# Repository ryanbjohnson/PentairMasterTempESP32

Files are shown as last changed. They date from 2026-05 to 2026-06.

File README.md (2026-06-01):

# Pentair MasterTemp ESP32 Interface

Open hardware and firmware-planning repository for a draft ESP32-based operating-control interface for the Pentair MasterTemp 125 heater family.

This project is early-stage engineering work. It is not a finished product, not certified, and not approved for connection to a live gas appliance.

## Safety First

- Read [DISCLAIMER.md](DISCLAIMER.md) before using any design file in this repository.
- Do not route or apply line voltage on this PCB.
- Do not add any ESP32-controlled gas-valve output.
- Preserve the OEM ignition control module and its sequencing.
- Keep the heat-request path fail-open with two normally-open relay contacts in series unless a qualified safety review approves a different architecture.
- Treat Wi-Fi, MQTT, Home Assistant, and firmware commands as advisory only. They must never override safety faults.
- A qualified technician and controls/electrical safety reviewer must approve any live-heater test.

## Current Status

The repository currently contains a KiCad scaffold and first-pass schematic capture for major control-board blocks:

- 24 VAC power entry and low-voltage rails.
- Operating-control/ICM interface and dual relay heat-request chain.
- ESP32 supervisor, watchdog, brownout, and relay-gate contract.
- Manual-aligned safety-stack input sheet and static safety gate.
- Field verification and OEM-board photo layout notes.

Remaining work includes final schematic capture, field verification, PCB/schematic parity cleanup, routing, FMEA, bench validation, and professional safety review.

## Repository Map

- `MasterTemp_ESP32_Interface_Preliminary_Design.md`: top-level design intent and safety boundary.
- `pcb/mastertemp_esp32/`: KiCad project.
- `pcb/mastertemp_esp32/docs/`: design notes, manual review, field verification, and layout notes.
- `pcb/mastertemp_esp32/references/`: project-local manuals and visual references used during review.
- `pcb/requirements/`: machine-readable requirements.
- `scripts/`: headless KiCad and test automation.
- `tests/`: scaffold and safety-boundary regression tests.

## Development Quick Start

Install KiCad 8 and Python 3, or use the included dev container.

Run checks:

```bash
./scripts/run-tests.sh
./scripts/kicad-check.sh
```

Open the KiCad project:

```bash
pcb/mastertemp_esp32/mastertemp_esp32.kicad_pro
```

Generated outputs go in ignored `reports/` and `fab/` directories.

## Contributing

Read [CONTRIBUTING.md](CONTRIBUTING.md) before opening issues or pull requests. Contributions that weaken the safety boundary, directly drive the gas valve, add line-voltage routing, or bypass the OEM ignition control module will not be accepted.

Useful first contributions:

- Improve field-verification checklists and documentation.
- Capture missing schematic detail with clear review stubs where assumptions remain open.
- Reduce ERC/DRC/parity issues without masking safety problems.
- Improve tests that enforce the safety boundary.
- Review connector pinout assumptions against installed-heater evidence.

## Security And Safety Reports

Report safety or security issues using GitHub private vulnerability reporting when available, or follow [SECURITY.md](SECURITY.md). Do not publish exploit steps, unsafe bypass instructions, or live-appliance test procedures in public issues.

## License

This repository is licensed under the MIT License. See [LICENSE](LICENSE).

Before first public hardware release, the project owner may choose to move hardware design files to a hardware-specific license such as CERN-OHL-S-2.0; see [docs/licensing.md](docs/licensing.md).

## Publishing Checklist

Before making the repository public or tagging a release, review [docs/open_source_release_checklist.md](docs/open_source_release_checklist.md).

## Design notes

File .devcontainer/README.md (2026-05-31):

# Dev Container Troubleshooting

This dev container is for headless KiCad CLI checks and exports. Use native KiCad on Windows for the GUI.

## KiCad version

The container installs KiCad from the official `ppa:kicad/kicad-8.0-releases` PPA and verifies `kicad-cli` reports version `8.x` during the image build. Rebuild the container after changing `.devcontainer/Dockerfile`:

```text
Dev Containers: Rebuild Container
```

After rebuild, confirm:

```bash
kicad-cli version
```

It should print an `8.x` version. The checked-in PCB file requires KiCad 8 or newer.

## Error: Server is null / cannot connect to docker.sock

Example:

```text
"Server":null
failed to connect to the docker API at unix:///var/run/docker.sock
```

This means VS Code found a Docker client, but no Docker daemon is reachable from the environment where the Dev Containers extension is running.

On Windows with Docker Desktop:

1. Start Docker Desktop.
2. Wait until it says the engine is running.
3. In PowerShell, run:

   ```powershell
   docker version
   docker context ls
   ```

4. If using WSL, enable Docker Desktop WSL integration:

   Docker Desktop -> Settings -> Resources -> WSL Integration -> enable your distro.

5. Restart WSL and VS Code:

   ```powershell
   wsl --shutdown
   ```

6. Reopen this folder in VS Code and rebuild the container.

If the folder is opened through WSL, also check inside that WSL distro:

```bash
docker version
ls -l /var/run/docker.sock
```

The Docker client should show a non-null `Server` section before the dev container can build.

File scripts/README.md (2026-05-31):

# KiCad Scripts

These scripts assume `kicad-cli` is available.

On Windows, install KiCad natively and add its `bin` directory to PATH, or use the VS Code dev container for headless checks.

Typical commands:

```powershell
.\scripts\kicad-check.ps1
.\scripts\kicad-export.ps1
.\scripts\open-kicad-project.ps1
```

Inside the dev container:

```bash
./scripts/run-tests.sh
./scripts/kicad-check.sh
./scripts/kicad-export.sh
```

The dev container is useful for repeatable ERC/DRC/export automation. It is not the preferred way to run the KiCad GUI on Windows.

If VS Code reports `"Server":null` or cannot connect to `/var/run/docker.sock`, Docker Desktop is not reachable from the environment running the Dev Containers extension. Start Docker Desktop, enable WSL integration if the folder is opened through WSL, then run `docker version` until it shows both `Client` and `Server` sections.

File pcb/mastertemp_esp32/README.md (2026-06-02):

# MasterTemp ESP32 KiCad Scaffold

This folder is the KiCad project area for the MasterTemp 125 ESP32 interface board.

The current files are a scaffold, not a completed schematic or board layout. The design intent and safety constraints live in:

- `../../MasterTemp_ESP32_Interface_Preliminary_Design.md`
- `../requirements/mastertemp_esp32_requirements.yaml`

Installed-heater inputs required before electrical release are tracked in `docs/field_input_verification.md`.

The original Pentair board photo reference is tracked in `docs/oem_board_photo_layout_notes.md`; save the image itself as `references/images/original_pentair_control_board_front.jpg` when exporting the chat/IDE attachment.

## Recommended workflow

1. Open `mastertemp_esp32.kicad_pro` in KiCad.
2. Immediately save the project from KiCad once, so your installed KiCad version normalizes the project metadata.
3. Work sheet by sheet, starting with `sheets/power_24vac.kicad_sch`.
4. After each sheet-level change, run ERC.
5. After placement/routing changes, run DRC.
6. Keep all project-local symbols in `libraries/symbols/mastertemp_esp32.kicad_sym`.
7. Keep all project-local footprints in `libraries/footprints/mastertemp_esp32.pretty`.

## Safety notes

- This project is an operating-control interface only.
- Do not add any ESP32-controlled gas-valve output.
- Do not route line voltage on this PCB.
- Preserve the OEM ignition control module and its sequencing.
- The heat-request output must remain dual normally-open relay contacts in series unless a qualified safety review approves another architecture.

## Folder map

- `sheets/`: hierarchical schematic sheets.
- `libraries/`: project-local symbols and footprints.
- `rules/`: layout constraints and DRC notes.
- `docs/`: design workflow notes, pin maps, and review records.
- `references/`: project-local manuals, source documents, and non-release visual references.

## Completion checklist

Use this as the live gate list for moving from scaffold to a reviewable PCB package. Keep each checkbox honest: complete means captured, checked, and reviewed, not merely started.

### Project setup

- [x] KiCad project scaffold exists with root schematic, child sheets, PCB file, local library tables, and scripts.
- [x] Four-layer board scaffold exists with preliminary 160 mm x 100 mm outline and functional placement zones.
- [x] PCB floorplan v0 exists with connector, relay, power, ESP32, analog, and test-pad placement envelopes.
- [x] Local MasterTemp 125 Rev C PDF electrical pages were reviewed and summarized in `docs/mastertemp125_rev_c_manual_review.md`.
- [x] Candidate sourced BOM and first-pass footprint placement exist for control-board circuitry.
- [x] PCB-side draft nets and first-pass relay contact-chain routing are applied and documented.
- [x] Headless KiCad `ERC` and `DRC` automation runs in the dev container.
- [x] Repository-level scaffold tests exist under `tests/`.
- [ ] KiCad project metadata has been opened and normalized once in the target GUI KiCad version.
- [ ] Generated `reports/` and `fab/` outputs are regenerated from the final release candidate.

### Inputs to close before electrical release

- [ ] Exact MasterTemp 125 model revision, serial/date range, and connected/non-connected variant are recorded.
- [ ] Field input verification record is complete and reviewed in `docs/field_input_verification.md`.
- [x] Rev C manual connector groups are reflected in draft requirements and floorplan.
- [ ] Heater harness pinout is verified from the installed unit and matching manual revision.
- [ ] 24 VAC transformer no-load and loaded voltages are measured.
- [ ] Water thermistor resistance curve is confirmed.
- [ ] Stack flue sensor electrical type and valid/fault ranges are confirmed.
- [ ] Enclosure, mounting holes, standoff height, cable-entry direction, and service clearances are selected.
- [ ] Certification/review path is chosen, including current applicable pool-heater and automatic-control standards.

### Schematic capture

- [ ] `power_24vac`: connector, fuse/PTC, MOV/TVS, bridge, VRAW bulk, 5 V supply, 3.3 V supply, power-good/brownout.
- [ ] `icm_interface`: manual-aligned operating-control connector, dual series normally-open relay contacts, coil drivers, flyback, AC opto sense, TH feedback, ICM terminal reference.
- [ ] `esp32_supervisor`: ESP32 module, programming header, watchdog, reset supervisor, I2C, relay-enable logic.
- [ ] `safety_inputs`: Fireman's Switch, PS, HLS, ES1, AGS static chain, AFS dynamic monitor, dry-contact isolated sense.
- [ ] `thermistor_sfs`: first-pass ADC/window-comparator architecture captured; final thermistor/SFS values and thresholds remain field-open.
- [ ] `ui_remote`: Pool/Common/Spa external-control dry-contact sense only; keypad/display/buzzer/status LED design remains out of scope.
- [ ] ERC has zero unreviewed violations after each sheet is captured.
- [ ] All symbols have footprints assigned or documented as no-fit/test-only.

### Safety review

- [ ] OEM ignition control module remains responsible for ignition, flame proving, and gas-valve sequencing.
- [ ] No ESP32 or board output can directly energize the gas valve.
- [ ] No line-voltage nets, connectors, labels, or routing exist on this PCB.
- [ ] Two normally-open relay contacts are in series in the `TH` heat-request path.
- [ ] Relay drive drops out on ESP32 reset, watchdog timeout, brownout, firmware fault, OTA, static safety open, invalid sensor, and relay feedback fault.
- [ ] AFS is treated as a dynamic airflow-proving input, not as a static pre-fire interlock.
- [ ] Preliminary FMEA covers welded relay, optocoupler failure, stuck ADC, brownout oscillation, firmware deadlock, and miswire cases.

### PCB layout

- [x] First-pass placement envelopes follow the zone plan in `rules/layout_constraints.md`.
- [x] Draft connector envelopes follow Rev C Figure 24 operating-control groups.
- [x] Candidate footprints are placed according to first-pass sourced part numbers.
- [x] Critical relay contact-chain PCB nets are named and first-pass routed.
- [ ] Footprints are synchronized to final schematic symbols and netlist.
- [x] ESP32 antenna keepout has no copper, components, or nearby metal-obstructing placement in the draft placement.
- [ ] Relay contact and 24 VAC control paths use assigned net classes and visible separation from logic.
- [ ] Field-side optocoupler pins face connectors and logic-side pins face MCU/expander circuitry.
- [ ] Thermistor/SFS analog traces avoid relay coils, AC sense, ESD discharge paths, and buck switch nodes.
- [x] Test pads exist for `VRAW`, `+5V`, `+3V3`, watchdog, safety chain, relay coils, TH feedback, and VAL sense.
- [x] Silkscreen warnings are present and readable.
- [x] DRC has zero unreviewed violations and schematic parity passes for the current draft.

### Fabrication and validation

- [ ] Schematic PDF, PCB plots, Gerbers, drill files, BOM, and placement outputs are generated.
- [ ] Bench test procedure is executed with an isolated 24 VAC transformer.
- [ ] Every required heat-request drop-out case is tested and recorded.
- [ ] Relay feedback/welded-contact detection is tested.
- [ ] `VAL` sense-only behavior is tested.
- [ ] 24-hour relay/sensor soak test is completed.
- [ ] Qualified technician review is complete before any live-heater connection.

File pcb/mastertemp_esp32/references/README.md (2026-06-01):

# References

Project-local reference materials live here.

- `manuals/`: vendor manuals, datasheets, and other source documents used for design review.
- `images/`: visual references such as original-board photos, connector photos, and field-verification images.

Reference materials support design review only. They do not close release gates unless the relevant field-verification record identifies the source, evidence, and reviewer.

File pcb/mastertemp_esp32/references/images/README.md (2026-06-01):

# Reference Images

Keep non-release visual references for board review here.

Expected files:

- `original_pentair_control_board_front.jpg`: user-provided front-side photo of the original MasterTemp 125/Pentair control board, received 2026-06-01. This chat attachment was analyzed in `../../docs/oem_board_photo_layout_notes.md`; save the original image here when exporting attachments from the chat or IDE.

These images are design references only. Do not treat markings, connector order, or component values from a photo as verified release data without matching them against the installed heater and manual revision.

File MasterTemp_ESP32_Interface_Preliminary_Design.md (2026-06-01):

# Pentair MasterTemp 125 ESP32 Interface Board - Preliminary Design Package

Status: preliminary engineering design for review only. This is not a certified gas-appliance control, not a release-to-manufacturing package, and not an installation instruction. A licensed/qualified pool-heater service technician and a controls engineer familiar with ANSI Z21.56/CSA 4.7 gas-fired pool-heater requirements must review, test, and approve any hardware before it is connected to a live heater.

## 1. Safety Boundary

This design is an operating-control/interface board. It must preserve the factory ignition control module (ICM) and must not directly drive the gas valve. The board only requests heat by switching the existing 24 VAC call-for-heat signal to `TH` on the ICM through isolated, normally-open relay contacts.

Hard requirements:

- No line voltage is routed on this PCB.
- No output from the ESP32 is allowed to energize the gas valve.
- Loss of ESP32 power, watchdog heartbeat, 3.3 V rail, 5 V rail, 24 VAC input, or firmware control opens the heat request.
- Two normally-open relay contacts are placed in series in the `TH` call-for-heat path.
- Hardware interlocks disable heat independently of MQTT, Wi-Fi, web UI, Home Assistant, and OTA.
- Safety switches are never bypassed in firmware.
- Final installation must keep the OEM heater grounding/bonding and line-voltage compartment unchanged.

Manufacturer facts used for this design:

- The MasterTemp 125 is a 120/240 VAC gas-fired heater using a Class II 24 VAC transformer for the control system.
- The Pentair manual identifies `VAL`, `TH`, `IND`, `GND`, `24VAC`, `FS`, thermistor, safety-switch, membrane-pad, and external pool/spa/common interface points.
- Pentair documents that the Fireman's Switch completes the heater 24 V AC control-board circuit, is sized around 24 VAC at 0.5 A, and must not receive line voltage.
- Pentair troubleshooting checks for 24 VAC between `TH` and `GND` immediately after a call for heat, and for 24 VAC on `VAL`/gas-valve-related signals only during the ignition trial.
- Pentair's connected-heater parts matrix lists old control board `42002-0007S` as basic PCBA superseded by kit `461105`; the older ICM `42001-0052S` is superseded by `476223`.

Sources:

- Pentair MasterTemp 125 Installation and User's Guide, Rev. C: https://www.pentair.com/content/dam/extranet/aquatics/pool-pad-pro-assets/heaters-%26-heat-pumps/inground-heaters/mastertemp-125-heater/MasterTemp%20125%20Installati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
  - Local checked-in copy: `pcb/mastertemp_esp32/references/manuals/mastertemp_125_installation_users_guide_english_rev_c.pdf`
- Pentair MasterTemp/Max-E-Therm connected-heater parts matrix: https://www.pentair.com/content/dam/extranet/nam/pentair-pool/residential/parts-sheets/heaters/mastertemp-max-e-therm-parts-matrix-connected-heater-update-v1.pdf
- Pentair electrical-system replacement parts sheet showing 42002-0007S and factory sensors: https://www.pentair.com/content/dam/extranet/nam/pentair-pool/residential/parts-sheets/heaters/MaxETherm_Heater_Electrical_System.pdf

## 2. System Architecture

Functional blocks:

1. 24 VAC input protection and power conversion.
2. ESP32-WROOM controller with external watchdog/supervisor.
3. Isolated 24 VAC sense inputs for ICM and heater-status signals.
4. Protected dry-contact sensing for remote Pool/Common/Spa and local UI.
5. Safety-switch sensing and hardware heat-enable chain.
6. Thermistor and stack-flue-sensor analog measurement through protected ADC channels.
7. Dual series relay heat-request output to ICM `TH`.
8. Relay feedback sensing for welded-contact or unexpected `TH` voltage detection.
9. Local UI header, optional OLED/I2C display, LEDs, buzzer, UART/JTAG programming.

Important sequencing note: `AFS` is a proving switch. It is expected to prove combustion-air flow after blower operation begins, so the firmware must check it for sane idle/run behavior instead of blindly requiring it closed before the call for heat. The hardware chain should include Fireman's Switch/remote enable, water pressure, high-limit, AGS, and analog overtemperature comparators as static pre-fire enables. `AFS` is monitored dynamically and can be included in a delayed run-enable circuit only after blower/IND activity is detected.

## 3. Schematic-Level Design

### Page 1 - 24 VAC Input and Power

Connector `J1 POWER`, 3.5 or 5.08 mm keyed pluggable terminal:

| Pin | Net | Description |
| --- | --- | --- |
| 1 | `VAC24_A` | Heater transformer secondary |
| 2 | `VAC24_B` | Heater transformer secondary |
| 3 | `CHASSIS_SHIELD` | Optional shield/bond reference, no DC tie by default |

Power path:

- `VAC24_A` -> `F1` 0.5 A fuse/PTC -> `MOV1` across `VAC24_A_FUSED`/`VAC24_B`.
- `D1` bridge rectifier converts `VAC24_A_FUSED`/`VAC24_B` to `VRAW`/`PGND_RAW`.
- `TVS1` bidirectional or post-bridge TVS clamps transients.
- `C1/C2` bulk capacitance on `VRAW`; use 63 V or 100 V ratings.
- `U1` high-voltage buck: `VRAW` to `+5V`.
- `U2` synchronous buck: `+5V` to `+3V3`.
- `U3` 3.3 V reset supervisor drives `ESP32_EN` and `HEAT_ENABLE_HW`.
- `U4` watchdog supervisor requires ESP32 heartbeat before relay drive is allowed.

Nominal voltage calculation:

- 24 VAC RMS nominal gives about 34 V peak before bridge drops.
- 24 VAC at +10 percent gives about 37 V peak.
- Unloaded Class II transformers can exceed nominal; all `VRAW` parts should be 63 V minimum, with the 5 V buck rated 80-100 V.

### Page 2 - MCU, Supervisors, and Digital I/O

Controller:

- `U5`: Espressif `ESP32-WROOM-32E-N16`.
- `U6`: Microchip `MCP23017-E/SS` I/O expander for LEDs, buttons, and non-time-critical opto inputs.
- `U7`: TI `ADS1115IDGSR` external ADC for thermistor, SFS, and rail monitoring.
- `U16/U17`: hardware window comparators for thermistor and SFS plausibility gates.

Supervisor logic:

- ESP32 outputs `WDI_HEARTBEAT` at 10-50 Hz only while the firmware is in a healthy non-OTA runtime loop.
- `U4 /WDO` must be inactive for heat enable.
- `U3 /RESET` must be inactive for heat enable.
- Relay drive is permitted only when:
  `HEAT_CMD_GPIO` AND `WATCHDOG_OK` AND `BROWNOUT_OK` AND `SAFETY_STATIC_OK` AND `NOT_OTA` AND `NOT_FAULT_LOCKOUT`.

Recommended hardware implementation:

- Use a small logic gate such as `SN74LVC1G08DBVR` for each relay-enable path.
- Use pull-downs on every relay-driver MOSFET gate.
- Make default gate state low during ESP32 reset/boot.

### Page 3 - Safety Inputs and Static Hardware Chain

Use two circuits for each safety contact where practical:

1. A low-current isolated sense input so firmware knows which safety opened.
2. A hardware safety-enable path so the relay coil cannot energize if a critical safety is open.

Critical static chain:

`FIREMAN_CLOSED` -> `PS_CLOSED` -> `HLS_CLOSED` -> `AGS_CLOSED` -> `ES1_CLOSED_OR_JUMPERED` -> `THERMISTOR_RANGE_OK` -> `SFS_RANGE_OK` -> `SAFETY_STATIC_OK`.

Notes:

- `PS` should close only with valid pump flow/pressure.
- `HLS` and `AGS` are closed in normal operation and open on overtemperature.
- `ES1` is spare; follow the exact heater wiring diagram for whether it is jumpered.
- `SFS` is not a simple low-resistance dry contact in all variants; treat it as an analog/high-impedance sensor and verify against the exact heater harness.
- `AFS` is dynamic. Firmware must confirm "open when idle" and "closed after blower/IND proves airflow." If `AFS` opens during firing, drop `TH` immediately.

Per-contact sense circuit, dry contact:

- Isolated 5 V wetting source `+5V_ISO` from `U8` isolated DC/DC.
- Contact closure drives an optocoupler LED through 2.2 k to 4.7 k.
- Optocoupler transistor pulls an ESP32/MCP23017 input low.
- Add 100 nF debounce capacitor on the logic side, then debounce again in firmware.
- Add ESD/TVS at harness connector.

### Page 4 - Thermistor and Stack Flue Sensor

Thermistor input:

- `J3_THERM_A/B` two-pin protected input.
- 10.0 k, 0.1 percent pull-up to `+3V3_ADC`.
- 1 k series resistor into `ADS1115_AIN0`.
- 100 nF C0G/X7R to analog ground at ADC pin.
- Low-leakage ESD clamp to rails.
- Firmware rejects open, short, out-of-range, implausible rate-of-change, and ADC saturation.
- Independent window comparator output `THERMISTOR_RANGE_OK` must drop heat enable on open, short, or overtemperature threshold even if firmware is stuck.

SFS input:

- `J3_SFS_A/B` two-pin protected high-impedance input.
- Use a high-value divider/current source suitable for the installed SFS type.
- Buffer with low-bias op amp before ADC if the selected excitation impedance is above 1 Mohm.
- Add a hardware comparator window `SFS_RANGE_OK` so extreme SFS open/short/fault disables heat without firmware.
- Final resistor values must be validated with the exact Pentair SFS installed on the heater.

### Page 5 - 24 VAC Sense Inputs

Use AC-input optocouplers for:

- `ICM_TH_SENSE`
- `ICM_IND_SENSE`
- `ICM_VAL_SENSE`
- `ICM_24VAC_SENSE`
- Optional `TH_OUTPUT_FEEDBACK`

Typical circuit:

- Field signal pair -> two series input resistors -> `H11AA1M` input.
- Start value: 2 x 12.1 k, 0.25 W, 1 percent in series for a 24 VAC signal.
- Logic transistor side: 10 k pull-up to 3.3 V, Schmitt input or RC pulse stretcher.
- Firmware treats AC sense as a pulse train and declares signal present only after several valid half-cycles.

Do not use these sense circuits to source current into the ICM. They are monitor-only.

### Page 6 - Call-for-Heat Output

The heat-request output is a dry, isolated, dual-relay series path:

`ICM_24VAC_SOURCE` -> `K1_COM` -> `K1_NO` -> `K2_COM` -> `K2_NO` -> `ICM_TH`.

Relay gating:

- `K1` coil: controlled by firmware heat command plus watchdog/brownout gate.
- `K2` coil: controlled by static safety hardware chain plus firmware heat command gate.
- Both relays are normally open.
- Loss of board power opens both relays.
- A stuck relay is detected by `TH_OUTPUT_FEEDBACK` when firmware expects off.

Relay contact rating:

- Minimum 30 VAC / 1 A resistive.
- Use relays with substantially higher agency-rated contact capacity where possible.
- Contacts are switching only the heater's 24 VAC control circuit, never line voltage.

Gas valve:

- No board output is provided for direct gas-valve drive.
- `VAL` is monitor-only through an isolated AC sense input.

### Page 7 - External Controls and UI

Remote Pool/Common/Spa:

- `POOL_REMOTE`, `COMMON_REMOTE`, `SPA_REMOTE` are dry-contact sense inputs.
- The board supplies wetting current through isolated sensing only.
- Do not accept externally supplied voltage on these terminals.
- If Pool and Spa are both asserted, enter conflict fault and keep heat off.

Local controls:

- `BTN_POOL`
- `BTN_SPA`
- `BTN_OFF`
- `BTN_UP`
- `BTN_DOWN`
- `BTN_RESET_SERVICE`

Display:

- I2C OLED/LCD header on `DISPLAY_SDA`, `DISPLAY_SCL`, `+3V3`, `GND`.
- Optional buzzer and WS2812/status LED header, powered from `+5V` with level-shifted data if used.

## 4. Connector Pinout Table

### J1 - Power

| Pin | Signal | Type |
| --- | --- | --- |
| 1 | `24VAC_IN_1` | 24 VAC transformer secondary |
| 2 | `24VAC_IN_2` | 24 VAC transformer secondary |
| 3 | `CHASSIS_SHIELD` | Shield/bond reference, normally isolated from logic |

### J2 - Ignition Control Module Interface

| Pin | Signal | Type |
| --- | --- | --- |
| 1 | `ICM_24VAC_SOURCE` | 24 VAC source for relay contact COM |
| 2 | `ICM_GND_REF` | 24 VAC reference for sense only |
| 3 | `ICM_TH_OUT` | Relay-switched 24 VAC call for heat to TH |
| 4 | `ICM_TH_SENSE_A` | Isolated AC sense |
| 5 | `ICM_IND_SENSE_A` | Isolated AC sense |
| 6 | `ICM_VAL_SENSE_A` | Isolated AC sense |
| 7 | `ICM_SENSE_REF` | Return/reference for AC sense inputs |

### J3 - Safety and Sensors

Use paired terminals where possible so the board can preserve the field wiring instead of relying on chassis/common returns.

| Pin | Signal | Type |
| --- | --- | --- |
| 1 | `PS_A` | Water pressure switch |
| 2 | `PS_B` | Water pressure switch |
| 3 | `HLS_A` | High-limit switch |
| 4 | `HLS_B` | High-limit switch |
| 5 | `ES1_A` | Extra switch/jumper |
| 6 | `ES1_B` | Extra switch/jumper |
| 7 | `AFS_A` | Air-flow proving switch |
| 8 | `AFS_B` | Air-flow proving switch |
| 9 | `AGS_A` | Automatic gas shutoff switch |
| 10 | `AGS_B` | Automatic gas shutoff switch |
| 11 | `SFS_A` | Stack flue sensor |
| 12 | `SFS_B` | Stack flue sensor |
| 13 | `THERM_A` | Water thermistor |
| 14 | `THERM_B` | Water thermistor |

### J4 - Remote Controls

| Pin | Signal | Type |
| --- | --- | --- |
| 1 | `POOL_REMOTE` | Dry-contact sense |
| 2 | `COMMON_REMOTE` | Dry-contact common |
| 3 | `SPA_REMOTE` | Dry-contact sense |
| 4 | `FIREMAN_A` | Fireman's Switch loop |
| 5 | `FIREMAN_B` | Fireman's Switch loop |

### J5 - Local UI

| Pin | Signal | Type |
| --- | --- | --- |
| 1 | `BTN_POOL` | Momentary input |
| 2 | `BTN_SPA` | Momentary input |
| 3 | `BTN_OFF` | Momentary input |
| 4 | `BTN_UP` | Momentary input |
| 5 | `BTN_DOWN` | Momentary input |
| 6 | `BTN_RESET` | Momentary input |
| 7 | `UI_GND` | Logic ground |
| 8 | `DISPLAY_SDA` | I2C |
| 9 | `DISPLAY_SCL` | I2C |
| 10 | `+3V3_UI` | Display/UI power |
| 11 | `BUZZER` | Output |
| 12 | `STATUS_LED_DATA` | Output |

### J6 - Programming/Service

| Pin | Signal |
| --- | --- |
| 1 | `+3V3` |
| 2 | `GND` |
| 3 | `ESP_TX0` |
| 4 | `ESP_RX0` |
| 5 | `EN` |
| 6 | `GPIO0_BOOT` |

## 5. Candidate BOM

This BOM is a starting point for schematic capture. It is not procurement-approved; verify package, availability, lifecycle, agency ratings, and derating before layout release.

| Ref | Qty | Part number | Manufacturer | Function |
| --- | --- | --- | --- | --- |
| U5 | 1 | `ESP32-WROOM-32E-N16` | Espressif | Wi-Fi MCU module |
| U1 | 1 | `LM5164YDRCR` | Texas Instruments | 100 V input buck, 5 V rail |
| U2 | 1 | `AP63203WU-7` | Diodes Inc. | 5 V to 3.3 V buck |
| U3 | 1 | `TPS3839G33DBZR` | Texas Instruments | 3.3 V brownout supervisor |
| U4 | 1 | `TPS3823-33DBVR` | Texas Instruments | Watchdog/reset supervisor |
| U6 | 1 | `MCP23017-E/SS` | Microchip | I/O expander |
| U7 | 1 | `ADS1115IDGSR` | Texas Instruments | 16-bit I2C ADC |
| U8 | 1 | `NXE1S0505MC-R7` | Murata | Isolated 5 V for dry-contact wetting |
| U16-U17 | 2 | `TLV6700DDCR` | Texas Instruments | Window comparators for sensor validity gates |
| U18 | 1 | `OPA333AIDBVR` | Texas Instruments | Low-bias analog buffer for SFS if needed |
| U9-U12 | 4 | `H11AA1M` | onsemi | AC optocoupler sense |
| U13-U15 | 3 | `TLP293-4(GB,E)` | Toshiba | Quad optocouplers for dry contacts |
| K1-K2 | 2 | `G5V-1-DC5` | Omron | Series NO heat-request relays |
| Q1-Q2 | 2 | `AO3400A` | Alpha & Omega | Relay low-side drivers |
| D1 | 1 | `MB10S-13-F` | Diodes Inc. | Bridge rectifier |
| D2-D3 | 2 | `SS14` | Vishay/Diodes Inc. | Relay flyback diodes |
| F1 | 1 | `0451.500MRL` | Littelfuse | 0.5 A input fuse |
| MOV1 | 1 | `V47ZA1P` | Littelfuse | 24 VAC surge clamp |
| TVS1 | 1 | `SMBJ51CA` | Littelfuse | Post-bridge transient clamp |
| C1 | 1 | `EEU-FR1J471L` | Panasonic | 470 uF, 63 V bulk capacitor |
| C2-C3 | 2 | `CGA5L3X7R2A475K160AE` | TDK | 4.7 uF, 100 V input ceramic |
| L1 | 1 | `744773470` | Wurth Elektronik | 47 uH buck inductor, validate with U1 |
| L2 | 1 | `74438323022` | Wurth Elektronik | 2.2 uH buck inductor |
| R_AC | 8 | 12.1 k, 0.25 W, 1% | Yageo/Vishay | AC opto input resistors, two per sense |
| R_WET | as needed | 2.2 k to 4.7 k, 0.1 W | Yageo/Vishay | Dry-contact opto LED resistors |
| R_TH | 1 | 10.0 k, 0.1%, 25 ppm | Vishay | Thermistor pull-up |
| R_GATE | 2 | 100 ohm | Any | MOSFET gate resistors |
| R_PD | 2 | 100 k | Any | Relay gate pull-downs |
| J1-J6 | as needed | Phoenix Contact MSTB/MC keyed pluggable series | Phoenix Contact | Field connectors |
| ENC | 1 | `1554H2GYCL` or similar | Hammond | Polycarbonate enclosure, gasketed |

Possible alternates:

- Use an ESP32-S3-WROOM module if more RAM, USB, or safer ADC isolation strategy is needed.
- Use force-guided safety relays if a certification path requires positively guided contacts and contact monitoring.
- Use a certified external 24 VAC to 5 V DC module instead of the onboard buck if thermal/EMC qualification becomes the bigger risk.

## 6. Firmware Pin Map

ESP32 pins:

| Signal | GPIO | Notes |
| --- | --- | --- |
| `I2C_SDA` | GPIO21 | ADS1115, MCP23017, OLED |
| `I2C_SCL` | GPIO22 | I2C clock |
| `HEAT_K1_CMD` | GPIO25 | Relay K1 command, gated in hardware |
| `HEAT_K2_CMD` | GPIO26 | Relay K2 command, gated in hardware |
| `WDI_HEARTBEAT` | GPIO27 | External watchdog input |
| `ICM_TH_PRESENT` | GPIO34 | Input-only, opto pulse |
| `ICM_IND_PRESENT` | GPIO35 | Input-only, opto pulse |
| `ICM_VAL_PRESENT` | GPIO32 | Opto pulse |
| `ICM_24VAC_PRESENT` | GPIO33 | Opto pulse |
| `MCP23017_INT` | GPIO39 | Input-only interrupt |
| `ADS1115_ALERT` | GPIO36 | Input-only alert |
| `BUZZER_PWM` | GPIO14 | Optional |
| `WS2812_DATA` | GPIO13 | Optional level-shifted LED |
| `UART0_TX` | GPIO1 | Service programming |
| `UART0_RX` | GPIO3 | Service programming |
| `BOOT` | GPIO0 | Bootloader only, pulled up |
| `EN` | EN | Supervisor reset |

Avoid using ESP32 strapping pins for relay commands. Relay outputs must remain deasserted during bootloader, reset, crash, OTA, and brownout.

MCP23017 allocation:

- GPA0-GPA5: local buttons.
- GPA6-GPA7: remote Pool/Spa conflict inputs.
- GPB0-GPB5: safety contact sense status.
- GPB6-GPB7: service/heating/status LEDs.

ADS1115 allocation:

- AIN0: water thermistor divider.
- AIN1: SFS measurement.
- AIN2: 5 V rail monitor.
- AIN3: VRAW scaled monitor or spare.

## 7. Firmware State Machine

### Power-up self-test

- Keep K1 and K2 off.
- Hold `WDI_HEARTBEAT` inactive until initialization completes.
- Validate NVS settings CRC and temperature calibration bounds.
- Validate thermistor range and ADC sanity.
- Validate SFS range and comparator state.
- Confirm no relay feedback is present with relay commands off.
- Confirm no conflicting Pool/Spa commands.
- Confirm AFS is in its expected idle state; a stuck AFS enters service fault.

### Idle

- Display current water temperature and selected mode.
- Publish MQTT telemetry.
- Monitor all safeties continuously.
- Permit OTA only in Idle and only when no post-purge or anti-short-cycle timer is active.

### Heat demand pending

Conditions required:

- Pool or Spa mode selected, not Off.
- Setpoint above measured water temperature plus hysteresis.
- Setpoint no higher than 104 deg F / 40 deg C default maximum.
- Fireman's Switch closed.
- Water pressure switch closed.
- HLS and AGS closed.
- Thermistor and SFS valid.
- No active lockout.
- Pool and Spa inputs not both active.
- Watchdog, brownout, and relay-feedback tests pass.

### Ignition sequence monitor

- Energize K1/K2 only after all gates are true.
- Confirm `TH` feedback appears.
- Watch `IND`/blower-related sense if connected.
- Require AFS to prove within a configured timeout after blower/IND activity.
- Monitor `VAL` as sense-only; do not drive it.
- If `VAL` appears when no valid `TH` command exists, enter service lockout.
- If ignition sequence times out, drop `TH`, log fault, and lock out or retry according to configured policy.

### Heating

- Maintain heat request only while all permissives remain true.
- Drop K1/K2 immediately on safety fault, thermistor/SFS invalid reading, overtemperature, watchdog event, brownout, relay-feedback mismatch, remote conflict, or user Off.
- Log runtime and ignition count.
- Publish heating state and active fault state over MQTT.

### Post-purge / cooldown

- Keep K1/K2 off.
- Continue monitoring blower/IND/VAL feedback.
- Do not re-fire until the post-purge observation has completed and the anti-short-cycle timer has expired.
- Manual default: 45 s blower/post-purge observation and 5 min anti-short-cycle delay.

### Fault lockout

Manual reset required for:

- High-limit or AGS fault.
- SFS invalid or overtemperature.
- Thermistor open/short/out-of-range.
- Watchdog reset while heating.
- Brownout while heating.
- Relay feedback indicates welded/stuck contact.
- `VAL` present without commanded heat.
- AFS stuck closed at idle or failure to prove after blower start.

Timed retry may be allowed only for benign demand/timeouts after professional review. Do not auto-retry high-limit, gas-valve, relay-feedback, or sensor-validity faults.

## 8. MQTT and Home Assistant

Suggested MQTT topics:

- `pentair/mastertemp125/state`
- `pentair/mastertemp125/availability`
- `pentair/mastertemp125/water_temp_f`
- `pentair/mastertemp125/pool_setpoint_f`
- `pentair/mastertemp125/spa_setpoint_f`
- `pentair/mastertemp125/mode/set`
- `pentair/mastertemp125/fault`
- `pentair/mastertemp125/runtime_seconds`
- `pentair/mastertemp125/ignition_count`

Rules:

- Wi-Fi failure must never block local safety operation.
- MQTT commands are advisory UI commands only; they cannot override a safety fault.
- OTA is refused unless state is Idle, heat relays are off, `VAL` is not present, and post-purge/anti-short-cycle timers are clear.
- Home Assistant discovery should expose climate control, binary sensors for safeties, and diagnostic sensors, but no entity should bypass local lockouts.

## 9. Power Budget

Estimated worst-case board load:

| Load | Voltage | Current | Power |
| --- | --- | --- | --- |
| ESP32 Wi-Fi burst | 3.3 V | 500 mA peak | 1.65 W peak |
| ESP32 average | 3.3 V | 120-180 mA | 0.4-0.6 W |
| Relays K1/K2 | 5 V | 60 mA total typical | 0.3 W |
| Optos/isolated wetting | 5 V | 50-100 mA | 0.25-0.5 W |
| OLED/status LEDs | 3.3/5 V | 50-150 mA | 0.2-0.6 W |
| Margin | - | - | 1 W |

Recommended supply ratings:

- 5 V rail: at least 1.2 A continuous.
- 3.3 V rail: at least 700 mA peak, 400 mA continuous.
- Thermal design: verify at 50 deg C ambient inside the heater control compartment.
- Brownout threshold: disable relays before ESP32 operation becomes undefined.

## 10. PCB Layout Requirements

Board stack:

- Prefer 4-layer PCB: signal/top, solid ground, power, signal/bottom.
- 2-layer acceptable only after EMC/noise testing, with short high-current loops and careful grounding.

Zones:

- Zone A: 24 VAC field wiring, fusing, bridge, surge protection.
- Zone B: `VRAW` buck converter and bulk capacitor.
- Zone C: logic/ESP32/ADC/I2C.
- Zone D: relay contacts and ICM connector.
- Zone E: external remote/UI field connector.

Clearance:

- No line voltage on PCB.
- Maintain at least 6.4 mm clearance between any connector area that could be miswired to field wiring and SELV logic where practical.
- Add isolation slots under/around optocouplers and relay contact areas.
- Maintain clear silkscreen boundary: "24 VAC CONTROL ONLY - NO LINE VOLTAGE".
- Keep ESP32 antenna beyond copper pour and away from relay/transformer wiring.

Routing:

- Route `VRAW` buck input loop compactly.
- Keep thermistor/SFS traces away from relay coils, buck switch node, and AC sense inputs.
- Use star/quiet analog ground into ADC reference region.
- Place TVS parts at connector entry.
- Put relay contacts in series with wide, separated traces; label COM/NO clearly.
- Provide test pads for `+5V`, `+3V3`, `VRAW`, `WATCHDOG_OK`, `SAFETY_STATIC_OK`, `K1_COIL`, `K2_COIL`, `TH_FEEDBACK`, `VAL_SENSE`.

Silkscreen warnings:

- "NO LINE VOLTAGE ON CONTROL TERMINALS"
- "GAS VALVE MONITOR ONLY - DO NOT DRIVE"
- "24 VAC CLASS II CONTROL POWER ONLY"
- "INSTALL/SERVICE BY QUALIFIED TECHNICIAN"
- "VERIFY WIRING AGAINST HEATER MANUAL BEFORE POWER"

## 11. Enclosure and Mounting

Recommended:

- Mount inside the existing low-voltage/control-board compartment only if line-voltage separation and temperature limits are preserved.
- Use a gasketed polycarbonate enclosure if mounted separately: Hammond `1554H2GYCL` or equivalent.
- Use nylon or metal standoffs with bonded ground only where required by heater enclosure practice.
- Do not tie ESP32 digital ground to chassis/bonding conductor unless an EMI/safety review intentionally adds a defined network, such as Y-cap/RC/TVS strategy allowed by applicable standards.
- All external wires should use 105 deg C rated insulation where they share routing with heater wiring, matching the manual's service guidance.

## 12. Bench Test Procedure

Before heater connection:

1. Visual inspect PCB for solder bridges, wrong polarity capacitors, and relay contact clearance.
2. Confirm no continuity between relay contact field nets and ESP32 logic ground.
3. Power from an isolated bench 24 VAC transformer only.
4. Verify `VRAW`, `+5V`, and `+3V3` at low, nominal, and high simulated transformer input.
5. Hold ESP32 in reset; confirm K1/K2 contacts remain open.
6. Load blank firmware or stop heartbeat; confirm watchdog disables relay drive.
7. Force brownout; confirm relay coils drop out before ESP32 resets unpredictably.
8. Command heat with safety chain open; confirm K1/K2 do not both close.
9. Simulate each safety input open/closed and verify correct diagnostic state.
10. Simulate AFS stuck closed at idle; confirm lockout.
11. Simulate blower/IND then AFS closure; confirm allowed sequence.
12. Simulate thermistor normal, open, short, high temperature, and implausible jumps.
13. Simulate SFS normal, open, short, and overtemperature/fault values.
14. Apply Pool and Spa remote contacts independently; confirm dry-contact behavior.
15. Assert Pool and Spa simultaneously; confirm conflict fault and no heat request.
16. Confirm relay output switches only isolated 24 VAC to `TH`, never line voltage.
17. With relays off, inject unexpected `TH` feedback; confirm welded-contact/external-voltage fault.
18. With `VAL` sense active and no heat command, confirm service lockout.
19. Confirm OTA is rejected during any non-idle state.
20. Run 24-hour soak test with cycling relays and synthetic sensors.

On-heater test, qualified technician only:

1. Compare every harness wire against the exact MasterTemp 125 wiring diagram revision for the installed heater.
2. Confirm line power is off and locked out before wiring.
3. Confirm no line-voltage conductor is present on any board terminal.
4. First power the board from heater 24 VAC with heat output disconnected.
5. Verify sensor readings and safety states match actual heater conditions.
6. Connect `TH` output with gas shut off/manual valve off for initial sequence testing.
7. Verify `TH` appears only during valid call for heat and drops immediately on each simulated safety opening.
8. Verify blower/IND and AFS sequence.
9. Verify `VAL` is monitored only and never driven by this board.
10. Restore gas only after wiring, safeties, post-purge, and shutdown behavior are verified.
11. Perform combustion, gas-pressure, leak, venting, and CO tests according to the heater manual and local code.

## 13. Safety Validation Checklist

- [ ] The OEM ICM remains installed and handles ignition, flame proving, and gas-valve sequencing.
- [ ] ESP32 cannot directly energize gas valve.
- [ ] K1 and K2 are normally open and series-connected in the `TH` request path.
- [ ] Relay contacts open with no board power.
- [ ] Relay contacts open with ESP32 reset.
- [ ] Relay contacts open with watchdog timeout.
- [ ] Relay contacts open with 3.3 V brownout.
- [ ] Relay contacts open with Fireman's Switch open.
- [ ] Relay contacts open with PS open.
- [ ] Relay contacts open with HLS or AGS open.
- [ ] Relay contacts open on invalid thermistor.
- [ ] Relay contacts open on invalid SFS.
- [ ] AFS stuck-closed-at-idle fault is detected.
- [ ] AFS failure-to-prove fault is detected.
- [ ] Pool/Spa simultaneous command fault is detected.
- [ ] Unexpected `TH` voltage with relays off is detected.
- [ ] Unexpected `VAL` voltage without heat request is detected.
- [ ] Wi-Fi/MQTT/Home Assistant cannot override safety lockout.
- [ ] OTA cannot run while heating, post-purge, or anti-short-cycle timer is active.
- [ ] Silkscreen and connector labels explicitly warn against line voltage.
- [ ] Final design has professional review and heater-specific wiring verification.

## 14. Open Items Before CAD Release

1. Confirm exact MasterTemp 125 revision, serial date, connected/non-connected version, and harness connector pinout.
2. Measure actual transformer no-load and loaded voltage in the installed heater.
3. Confirm thermistor resistance curve and SFS electrical characteristics for the installed sensor revision.
4. Decide whether this is a true replacement PCBA or an interposer that keeps parts of the OEM operating control.
5. Choose certification target and required standards before final relay/watchdog/safety-chain design.
6. Validate relay contact rating, creepage, and failure-mode requirements with the certification path.
7. Perform FMEA for relay welded contact, optocoupler failure, ADC stuck reading, brownout oscillation, and firmware deadlock.
8. Create actual KiCad/Altium schematic, PCB, ERC/DRC, fabrication drawings, test fixture, and firmware after the above are closed.

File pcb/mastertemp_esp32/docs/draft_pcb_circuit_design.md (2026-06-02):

# Draft PCB Circuit Design Pass

Date: 2026-06-02

Status: PCB-side draft routing and net assignment. This records the control-board circuit intent now applied to the board file by `scripts/apply-draft-pcb-nets.py`. Full release still requires symbol-level schematic capture and schematic-to-PCB synchronization.

## Scope

This pass covers the control board only:

- 24 VAC operating-control interface.
- Dual normally-open heat-request relay contacts in series.
- Sense-only diagnostic nets for `VAL`, `IND`, `TH`, `24VAC`, and `GAS`.
- External Pool/Common/Spa dry-contact input naming.
- Thermistor and SFS signal naming.
- ESP32, supervisor, ADC, I/O expander, relay-driver, and test-point net naming.

The keypad, membrane pad electronics, display, buzzer, and status LED remain out of scope.

## Applied Critical Contact Chain

| Function | PCB net | Applied pads |
| --- | --- | --- |
| ICM 24 VAC source into first relay contact | `ICM_24VAC_SOURCE` | `J2.5`, `K1.2` |
| Relay-to-relay series link | `HEAT_CHAIN_K1_K2` | `K1.3`, `K2.2` |
| Heat request output back to TH | `TH_HEAT_REQUEST_OUT` | `K2.3`, `J2.2` |

The first-pass board route connects the relay contact chain with 0.60 mm copper. `ICM_24VAC_SOURCE` is routed on `F.Cu`; `HEAT_CHAIN_K1_K2` and `TH_HEAT_REQUEST_OUT` are routed on `B.Cu` to avoid same-layer crossings with the relay coil and flyback routing.

## Applied Relay Driver Nets

| Function | PCB net | Applied pads |
| --- | --- | --- |
| K1 coil low-side node | `K1_COIL_LOW` | `K1.1`, `Q1.3`, `TP6.1` |
| K2 coil low-side node | `K2_COIL_LOW` | `K2.1`, `Q2.3`, `TP7.1` |
| Relay coil supply | `+5V_RELAY` | `K1.5`, `K2.5` |
| K1 gate drive placeholder | `RELAY_K1_GATE_DRIVE` | `R22.1` |
| K2 gate drive placeholder | `RELAY_K2_GATE_DRIVE` | `R23.1` |
| K1 gate command | `RELAY_K1_GATE` | `R22.2`, `Q1.1`, `R10.1` |
| K2 gate command | `RELAY_K2_GATE` | `R23.2`, `Q2.1`, `R11.1` |
| K1 gate pulldown return | `GND` | `R10.2` |
| K2 gate pulldown return | `GND` | `R11.2` |
| Driver source reference | `GND` | `Q1.2`, `Q2.2` |

The relay coil low-side traces, local `+5V_RELAY` rail between relay coil pins, K1/K2 flyback diode connections, MOSFET source grounds, first-pass relay-gate pulldowns, and first-pass relay-gate series resistors are routed. R10/R11/R22/R23 values remain TBD pending the ESP32/supervisor relay-drive review.

## Applied Low-Voltage Routing

- `VRAW` is first-pass routed from the bridge rectifier output to the local buck input capacitor, bulk reservoir capacitor, VRAW test point, U1 VIN pads, and the R28 raw-rail monitor top resistor.
- `PGND_RAW` is first-pass routed from the bridge rectifier return to the local buck input capacitor, bulk reservoir capacitor, and U1 PGND area with via-assisted local return stitching. The final high-current return shape still needs placement/layout review.
- `SW_5V` and `BST_5V` are first-pass routed through the 5 V buck switch/bootstrap loop, with the bootstrap net using a via-assisted back-layer hop to avoid the switch node.
- `+5V` is first-pass routed from the 5 V buck output/feed divider area to the 3.3 V regulator input decoupling node and TP2.
- `+3V3` is first-pass routed from the 3.3 V regulator output to its output capacitor, ADC supply, supervisor supply, ESP32 supply pad, 3.3 V test point, and the external-control Spa/Pool pullup resistor supply pads.
- `GND` now includes first-pass via-assisted routing from the ADC/local logic ground spine to the supervisor ground pins, ESP32 ground pad, relay-driver MOSFET sources, and the remote optocoupler/RC-filter ground cluster.
- `WATCHDOG_OK` is routed from the supervisor output to TP4 with a via-assisted back-layer hop around the local `+3V3` supervisor rail.
- `U6` is now schematic-owned as a local `MCP23017_SS` symbol. Its `VDD`, `VSS`, `SDA`, `SCL`, address pins, and reset pin are captured and first-pass routed; `A0`/`A1`/`A2` are tied low and `~RESET` is tied high. GPA0 is assigned to `VAL_OPTO_GPIO`, GPA1 is assigned to `TH_OPTO_GPIO`, GPA2 is assigned to `IND_OPTO_GPIO`, and GPA3 is assigned to `VAC24_OPTO_GPIO`; the remaining GPIO and interrupt pins remain explicitly no-connected until the expansion topology is assigned. R25/R26 add schematic-owned 0805 I2C pullup placeholders from `+3V3` to `I2C_SDA`/`I2C_SCL`, placed near U6 with short routed stubs to the shared U6/U7 bus.
- `VAC24_A_FUSED` now ties the fuse/MOV island to the bridge/TVS protection island using a back-layer bridge and front-layer via handoff.
- `VAL_SENSE_AC` is routed from J2 to TP9 as a perimeter diagnostic trace. It remains monitor-only and does not drive the gas valve.
- `REMOTE_SPA_SENSE` and `REMOTE_POOL_SENSE` are locally routed from their pullup resistors through the RC filter capacitors to the optocoupler output pins.
- `U8` is now schematic-owned as the Murata `NXE1S0505MC-R7` isolated 5 V converter. Per the NXE1 pin table, pad 1 is `GND`/`-Vin`, pad 3 is `+5V`/`+Vin`, pad 7 is `COMMON_LINE`/`-Vout`, pad 8 is `ISO_REMOTE_5V`/`+Vout`, and pad 14 remains no-connect. The isolated output is first-pass routed to the external-control wetting supply and common return.
- `U9`-`U12` now use a real project-local `H11AA1M` AC-input phototransistor optocoupler symbol instead of a generic DIP placeholder. The onsemi/Fairchild pinout is captured as pins 1-2 AC input, pin 3 NC, pin 4 emitter, pin 5 collector, and pin 6 base. `U11` has its VAL monitor transistor output side captured: emitter to `GND`, collector to `VAL_OPTO_GPIO` on MCP23017 GPA0, with R12 as a schematic-owned 0805 pullup placeholder to `+3V3`. Its AC input side is captured through two 0805 current-limit placeholders: `VAL_SENSE_AC` -> `R8` -> `VAL_OPTO_LIMIT_A` -> `R9` -> `VAL_OPTO_INPUT` -> `U11.1`, with `U11.2` returned to `ICM_GND_REF`. `U9` repeats that monitor pattern for TH: `TH_HEAT_REQUEST_OUT` -> `R13` -> `TH_OPTO_LIMIT_A` -> `R14` -> `TH_OPTO_INPUT` -> `U9.1`, with `U9.2` returned to `ICM_GND_REF`; U9 emitter returns to `GND`, collector connects to `TH_OPTO_GPIO` on MCP23017 GPA1, and R15 pulls the collector to `+3V3`. `U10` repeats the same pattern for IND: `IND_SENSE_AC` -> `R16` -> `IND_OPTO_LIMIT_A` -> `R17` -> `IND_OPTO_INPUT` -> `U10.1`, with `U10.2` returned to `ICM_GND_REF`; U10 emitter returns to `GND`, collector connects to `IND_OPTO_GPIO` on MCP23017 GPA2, and R18 pulls the collector to `+3V3`. `U12` now repeats the same sense-only pattern for the 24 VAC source: `ICM_24VAC_SOURCE` -> `R19` -> `VAC24_OPTO_LIMIT_A` -> `R20` -> `VAC24_OPTO_INPUT` -> `U12.1`, with `U12.2` returned to `ICM_GND_REF`; U12 emitter returns to `GND`, collector connects to `VAC24_OPTO_GPIO` on MCP23017 GPA3, and R21 pulls the collector to `+3V3`. R8/R9/R12/R13/R14/R15/R16/R17/R18/R19/R20/R21 final resistance, power/leakage, filtering, surge, and sensing margin remain review items.
- `R10` and `R11` are now schematic-owned 0805 relay-gate pulldown placeholders. They tie `RELAY_K1_GATE` and `RELAY_K2_GATE` to `GND` locally at Q1/Q2 so the MOSFET gates have a defined off-state once final drive values are selected. `R22` and `R23` are schematic-owned 0805 series-gate placeholders that split the schematic-only relay-gate logic outputs into `RELAY_K1_GATE_DRIVE`/`RELAY_K2_GATE_DRIVE` and the local MOSFET gate nodes.
- `SPA_LINE` and `POOL_LINE` are first-pass routed from the remote optocoupler input side to the external-control connector, `ISO_REMOTE_5V` is sourced from U8 and locally routed between the Spa/Pool remote wetting resistors, `COMMON_LINE` is sourced from U8 isolated return to J5.2, and the optocoupler LED anode nets are locally routed from the wetting resistors to the optocouplers.
- `U14` is now a schematic-owned thermistor AFE placeholder with a matching `SOT-23-6` PCB footprint. Its thermistor input, ADC output, window-sense, analog rail, and analog return nets are first-pass routed on the inner layers with short local pad escapes. R24 adds a schematic-owned 0805 thermistor pullup placeholder from `+3V3_ADC` to `THERMISTOR_ADC`, and C9 adds a schematic-owned 0805 ADC filter placeholder from `THERMISTOR_ADC` to `AGND`; both are locally routed near the U14/U7 analog cluster. Threshold/reference component values and the final thermistor/SFS analog topology remain review items.
- `U18` is the schematic-owned SFS buffer/excitation placeholder. R27 now reserves a routed 0805 series/protection element from the J3 `SFS_INPUT` field terminal to `SFS_FIELD_INPUT`, and C10 reserves a routed 0805 ADC-side filter from `SFS_ADC` to `AGND`. This keeps the SFS input path physically present while leaving the unknown `SFS_RETURN_OR_REF`, excitation, clamp strategy, and final value choices open until the installed SFS is characterized.
- ADS1115 AIN2 is now named and routed as `VRAW_MONITOR_ADC` instead of the stale `TH_FEEDBACK_ADC` label. R28 reserves the top divider resistor from `VRAW` near TP1, while R29 and C11 reserve the bottom divider/filter elements from `VRAW_MONITOR_ADC` to `AGND` in the analog cluster. The monitor node reaches U7 AIN2 with via-assisted inner-layer routing; final divider ratio, voltage/power ratings, leakage, filtering, and firmware scaling remain review items.
- R30/R31 add routed 0805 pullup placeholders from `+3V3` to `THERMISTOR_RANGE_OK` and `SFS_RANGE_OK` at U16/U17. These preserve physical pullup locations for the comparator outputs while leaving final values, population policy, output polarity, and static-safety logic review open.
- R32-R39 add routed 0805 threshold-divider placeholders from `+3V3_ADC` to `AGND` for the U16/U17 low/high comparator references. R32/R33 create `THERM_LOW_REF_TBD`, R34/R35 create `THERM_HIGH_REF_TBD`, R36/R37 create `SFS_LOW_REF_TBD`, and R38/R39 create `SFS_HIGH_REF_TBD`. These nets are routed into the comparator inputs with via-assisted local escapes; final resistor values, tolerances, hysteresis policy, and fault thresholds remain tied to measured thermistor/SFS curves and TLV6700 behavior.

## Applied Connector Nets

| Connector | Pad order |
| --- | --- |
| `J1` 24 VAC input | `24VAC_A`, `24VAC_B`, `EARTH_SHIELD_REF` |
| `J2` operating control | `VAL_SENSE_AC`, `TH_HEAT_REQUEST_OUT`, `IND_SENSE_AC`, `ICM_GND_REF`, `ICM_24VAC_SOURCE`, `FIREMAN_24VAC`, `FIREMAN_SWITCH_RETURN` |
| `J3` safety stack | `PS_SWITCH`, `HLS_SWITCH`, `ES1_SWITCH`, `AFS_SWITCH_DYNAMIC`, `AGS_SWITCH`, `SFS_INPUT`, `GAS_MONITOR_ONLY` |
| `J4` thermistor | `THERMISTOR_A`, `THERMISTOR_B` |
| `J5` external control | `SPA_LINE`, `COMMON_LINE`, `POOL_LINE` |

## Verification State

- ERC report: zero violations after the MCP23017 core-pin capture and placeholder ownership cleanup.
- PCB DRC report: zero violations and zero unconnected items after this pass.
- Silkscreen cleanup moved dense/internal references and long floorplan notes off the manufacturing silkscreen while preserving the notes in the board file.
- Schematic parity report: zero issues after bringing all currently placed footprints under schematic ownership. U6 now has its MCP23017 supply/I2C/address/reset core captured, U8 now has its isolated-supply input/output pins captured, U11 now has a routed VAL optocoupler input resistor chain, output to MCP23017 GPA0, and R12 logic-side pullup placeholder, U9 now has a routed TH optocoupler input resistor chain, output to MCP23017 GPA1, and R15 logic-side pullup placeholder, U10 now has a routed IND optocoupler input resistor chain, output to MCP23017 GPA2, and R18 logic-side pullup placeholder, U12 now has a routed 24 VAC optocoupler input resistor chain, output to MCP23017 GPA3, and R21 logic-side pullup placeholder, R10/R11 now have routed relay-gate pulldown placeholders, R22/R23 now have relay-gate series placeholders, R24/C9 now have routed thermistor divider/filter placeholders, R25/R26 now have routed I2C pullup placeholders, R27/C10 now have routed SFS input/filter placeholders, R28/R29/C11 now have routed VRAW monitor divider/filter placeholders, R30/R31 now have routed comparator-output pullup placeholders, R32-R39 now have routed comparator threshold-divider placeholders, and U9-U12 now have real H11AA1M pin identities. Conceptual relay-gate and static-safety review blocks are schematic-only so they no longer collide with physical optocoupler references.

## Next Real Electrical Work

- Continue replacing uncommitted placeholder blocks with real symbols, hierarchical pins, labels, footprints, and values.
- Assign remaining U6 MCP23017 GPIO/interrupt usage and review firmware-safe reset behavior; R25/R26 now reserve I2C pullup positions, but final values still depend on bus capacitance, speed, leakage, and any external pullups.
- Review and value the U11 VAL, U9 TH, U10 IND, and U12 24 VAC monitor input resistors, pullups, filtering, surge tolerance, CTR margin, and base-pin handling.
- Add/value remaining passives: buck feedback/compensation/filter parts, ADC protection, SFS return/excitation/buffer parts, comparator threshold/hysteresis values for R32-R39, and final values/ratings for the existing optocoupler, relay-gate, thermistor, I2C, SFS, and VRAW monitor placeholders.
- Run KiCad update-PCB-from-schematic and replace this PCB-side draft net application with schematic-derived nets.
- Complete schematic synchronization, copper zones, fabrication outputs, and qualified safety review.

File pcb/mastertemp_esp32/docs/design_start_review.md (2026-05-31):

# Design Start Review

Date: 2026-05-31

## Current Project State

This repository is a KiCad scaffold for a Pentair MasterTemp 125 ESP32 operating-control interface board. The system-level design intent is already well defined in `MasterTemp_ESP32_Interface_Preliminary_Design.md` and mirrored in `pcb/requirements/mastertemp_esp32_requirements.yaml`.

The KiCad project is not yet electrically captured. The root schematic contains six hierarchical sheets, but each child sheet currently contains only TODO notes. The project-local symbol library and footprint library are empty. The PCB file contains a 160 mm x 100 mm outline, four copper layers, net classes, and silkscreen zone labels, but no footprints, nets, or routed copper.

## Baseline Findings

- Safety boundary is clear: no line voltage, no direct gas-valve drive, preserve the OEM ignition control module, and switch only the 24 VAC `TH` call-for-heat path through two normally-open relay contacts in series.
- Requirements and documentation agree on the main sheet structure: power, ESP32/supervisor, ICM interface, safety inputs, thermistor/SFS, and UI/remote.
- Net classes already exist in the KiCad project for default logic, 24 VAC control, relay-contact 24 VAC, rectified VRAW, and sensor ADC routing.
- The board stackup is intended to be four-layer: top signal, inner ground, inner power, bottom signal.
- The current scripts expect newer KiCad CLI functionality. The installed CLI in this environment is KiCad 7.0.11, whose `sch` command does not support `erc`, so the existing check script cannot run here as written.

## Design Assumptions For First Pass

- Treat the board as an interposer/interface until the exact heater revision and harness pinout are confirmed.
- Keep the first board outline at the scaffold size of 160 mm x 100 mm while schematic capture proceeds.
- Use keyed pluggable field connectors for all heater-facing wiring, with grouped harness entry along the left/bottom service edges.
- Use standard KiCad symbols and footprints wherever possible. Add project-local symbols only for heater-specific connectors, labels, review blocks, or parts missing from the installed libraries.
- Keep the 24 VAC-derived supply onboard for the first electrical pass, but preserve the option to replace it with a certified DC module if EMC, thermal, or certification risk becomes dominant.

## First Schematic Pass

Capture in this order:

1. `power_24vac`: `J1_POWER`, input fuse/PTC, MOV/TVS, bridge, VRAW bulk capacitance, 5 V regulator placeholder, 3.3 V regulator placeholder, power-good/brownout outputs.
2. `icm_interface`: `J2_ICM`, dual series relay contacts, relay coil drivers, flyback diodes, AC optocoupler sense channels, and TH output feedback.
3. `esp32_supervisor`: ESP32 module, programming header, watchdog, reset supervisor, I2C pullups, relay-enable gate inputs, and bootstrap-safe relay command pins.
4. `safety_inputs`: dry-contact optocoupler sense channels, Fireman's Switch, static safety chain output, and a clearly separate dynamic AFS monitor.
5. `thermistor_sfs`: thermistor divider, SFS measurement placeholder, ADS1115, filter/protection, and hardware range comparator outputs.
6. `ui_remote`: remote Pool/Common/Spa dry-contact sense, local buttons, display header, buzzer, and status LED output.

## First PCB Floorplan

- Zone A, top-left: 24 VAC input, protection, rectifier, and VRAW bulk capacitor.
- Zone B, center-left: high-voltage buck converter and its compact switching loop.
- Zone C, right side: ESP32, watchdog, reset supervisor, ADC, I/O expander, display/UI logic, and I2C.
- Zone D, bottom-left: ICM connector and the two series heat-request relay contacts.
- Zone E, bottom/right edge: safety, sensor, remote, and UI connectors.
- Optocouplers sit across the field/logic boundary, with field pins toward connectors and logic pins toward the ESP32/MCP23017.
- Thermistor/SFS analog routing stays away from relay coils, buck switch node, AC optocouplers, and ESD return paths.

## Required Inputs Before Release

- Exact MasterTemp 125 revision and photographed/verified harness pinout.
- No-load and loaded voltage measurements from the heater 24 VAC transformer.
- Confirmed water thermistor curve and stack-flue-sensor electrical type.
- Enclosure choice, mounting holes, cable entry direction, standoff heights, and service clearance.
- Professional safety review/FMEA before connecting to a live heater.

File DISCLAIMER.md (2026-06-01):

# Safety Disclaimer

This repository contains experimental design files and documentation for an operating-control interface concept related to a gas-fired pool heater.

The project is not certified, not approved by Pentair, and not suitable for installation or connection to a live heater. It is not a replacement for the OEM control board, ignition control module, safety systems, service manual, or a qualified technician.

Pentair and MasterTemp are referenced only to identify the appliance family being studied. This project is independent and is not affiliated with, endorsed by, sponsored by, or approved by Pentair.

No file in this repository should be interpreted as:

- Appliance repair instructions.
- Installation instructions.
- Approval to modify a gas appliance.
- A certified safety design.
- Permission to bypass any factory safety device.
- Permission for unqualified live electrical, gas, ignition, combustion, or venting work.

Any future bench or live-heater work must follow the official manual for the exact installed model, local code, applicable standards, and qualified professional review.

The design must remain fail-open for heat request and must never directly drive the gas valve.

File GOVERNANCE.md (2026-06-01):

# Governance

This project is currently maintainer-led.

## Maintainer Responsibilities

Maintainers are responsible for:

- Preserving the documented safety boundary.
- Reviewing pull requests for technical quality and risk.
- Keeping release gates honest.
- Deciding when assumptions are sufficiently verified.
- Blocking changes that encourage unsafe installation, testing, or operation.

## Decision Making

Routine documentation, tests, and scaffold improvements can be merged after normal review.

Changes that affect heat-request behavior, relay topology, safety inputs, power isolation, field wiring, thermistor/SFS validity, watchdog/brownout behavior, or live-test procedure require explicit safety review before merge.

## Releases

No release should be described as installable, certified, production-ready, or safe for live-heater use until the checklist in `pcb/mastertemp_esp32/README.md` is complete and reviewed.

## Ownership

If additional maintainers are added, they should understand KiCad, embedded controls, and the project's gas-appliance safety boundary.

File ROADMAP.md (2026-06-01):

# Roadmap

This roadmap is planning guidance, not a promise of dates.

## Phase 1: Public Project Hygiene

- Root README and contributor documentation.
- Issue and pull-request templates.
- Safety/security reporting process.
- License decision.

## Phase 2: Complete First-Pass Schematic

- Finish `thermistor_sfs` capture.
- Finish `ui_remote` capture.
- Replace review stubs with documented circuits where field assumptions are closed.
- Maintain zero ERC violations.

## Phase 3: PCB Synchronization And Layout

- Synchronize footprints and netlist to the captured schematic.
- Resolve schematic/PCB parity findings.
- Route safety-critical heat-request and power nets.
- Preserve ESP32 antenna keepout and analog quiet zones.
- Reduce DRC findings to zero unreviewed violations.

## Phase 4: Verification Package

- Complete field input verification.
- Generate schematic PDF, plots, Gerbers, drill files, BOM, and placement outputs.
- Write bench-test and safety-review records.
- Run FMEA for relay, watchdog, brownout, sensor, optocoupler, firmware, and miswire faults.

## Phase 5: Review Before Any Live-Heater Work

- Qualified technician review.
- Controls/electrical safety review.
- Applicable standards review.
- Explicit project-owner approval for any live-heater test.

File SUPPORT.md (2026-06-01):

# Support

This repository does not provide appliance repair support, installation instructions, or emergency troubleshooting.

For heater service, gas, combustion, venting, electrical, or code-compliance questions, contact a qualified pool-heater technician and follow the official Pentair documentation for the exact installed model.

Use GitHub issues for:

- Repository setup problems.
- KiCad scaffold/test failures.
- Documentation improvements.
- Review of design assumptions.
- Non-urgent project planning.

Do not use GitHub issues for:

- Emergency heater problems.
- Requests to bypass safety systems.
- Live gas-valve, combustion, or ignition troubleshooting.
- Instructions for unqualified installation.

Safety or security-sensitive reports should follow `SECURITY.md`.

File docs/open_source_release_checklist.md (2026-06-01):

# Open Source Release Checklist

Use this before making the GitHub repository public.

## Repository Metadata

- [ ] Repository description clearly says this is an experimental KiCad/open hardware project.
- [ ] Repository topics include `kicad`, `esp32`, `open-hardware`, and `pool-heater` only if the owner is comfortable with discovery.
- [ ] GitHub private vulnerability reporting is enabled.
- [ ] Branch protection is enabled for `main`.
- [ ] Pull requests are required before merge.
- [ ] GitHub Actions checks are enabled.

## Documentation

- [ ] Root `README.md` is accurate.
- [ ] `CONTRIBUTING.md` reflects the desired contribution workflow.
- [ ] `SECURITY.md` has a real private reporting path.
- [ ] `LICENSE` matches the owner's intended license.
- [ ] `docs/licensing.md` decision is resolved if a hardware-specific license is preferred.
- [ ] `DISCLAIMER.md` is linked from project descriptions or release notes.
- [ ] Project-specific checklist in `pcb/mastertemp_esp32/README.md` is current.

## Safety And Privacy

- [ ] No private serial numbers, addresses, or identifying field photos are committed.
- [ ] No public docs instruct unqualified live-heater testing.
- [ ] No docs describe bypassing heater safety systems.
- [ ] The README clearly states the design is not certified or installable.
- [ ] Field input assumptions remain marked as open until verified.

## Generated Files

- [ ] `reports/` is not committed.
- [ ] `fab/` is not committed unless publishing a reviewed release package.
- [ ] KiCad backups, lock files, and local history are not committed.

## First Public Release

- [ ] Do not tag a hardware release until ERC, DRC, parity, field verification, FMEA, and safety review gates are complete.
- [ ] Use pre-release labels for any design snapshot before certified/reviewed hardware.
- [ ] Release notes repeat that the design is not approved for live-heater installation.

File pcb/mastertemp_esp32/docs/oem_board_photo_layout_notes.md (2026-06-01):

# OEM Board Photo Layout Notes

Date: 2026-06-01

Source: user-provided front-side photo of the original Pentair control board. Intended repo location: `../references/images/original_pentair_control_board_front.jpg`.

Status: visual reference only. The photo is useful for layout strategy, connector/service orientation, and major functional zoning. It is not sufficient evidence for final pin order, ratings, creepage, component values, or replacement-circuit approval.

## Visible Board Organization

- The board is a wide horizontal rectangle with four corner mounting holes and field/service connectors concentrated on the left, top, right, and bottom edges.
- A large relay occupies the upper-left corner, physically separated from the MCU and low-voltage logic. Its contact/load side appears near field wiring, with coil/drive circuitry just inside the board.
- Two tall left-edge harness connectors are stacked vertically. Their adjacent silkscreen and small opto/transistor groups indicate safety and operating-control sense inputs are routed inward from the service edge.
- The top edge has two multi-pin white harness connectors near the center. Their placement keeps field harnesses serviceable while short traces feed the MCU and support logic.
- The right edge carries a membrane/keypad-style connector and nearby status LED/button parts. This strongly suggests user-interface wiring is kept at the board perimeter.
- The switching supply is clustered in the upper-right quadrant: electrolytic capacitors, regulator IC, diode, inductor, and local passives are packed tightly together.
- The main microcontroller sits near the board center, with crystal immediately below and dense fanout to surrounding connectors and drivers.
- Test/program headers and a low-voltage pin header are along the lower edge, separated from high-current relay and supply areas.
- LED indicators are distributed along the lower and right portions, close to the functions they report.

## Layout Ideas To Carry Forward

- Preserve edge-serviceability: place all heater-facing connectors on board edges, with silkscreen labels readable from the service side.
- Keep relay/contact circuitry in a corner or edge zone, away from MCU, crystal, ADC, and sensor front ends.
- Route field input sense channels as short, parallel channels from the connector edge into identical optocoupler or protection cells. The OEM board appears to use repeated cells, which is good for review and troubleshooting.
- Keep the buck converter compact and self-contained: short input loop, diode/inductor/regulator/bulk cap close together, and no sensor traces through the switching-current loop.
- Place MCU centrally only if it reduces harness fanout length. For this ESP32 design, central logic is useful, but the antenna edge keepout may justify moving the ESP32 module toward a clear board edge while keeping helper ICs central.
- Keep crystal/clock parts tight to the MCU and away from relay, switching regulator, and long field traces.
- Put programming/test headers on a service edge, not buried between tall connectors or relay hardware.
- Keep diagnostic LEDs near the related connector or function, but do not let LED routing cut through isolation or analog-sensitive areas.
- Use the bottom edge for test pads and programming access, mirroring the OEM service/debug style.
- Maintain a visual and physical field-to-logic progression: connector edge, protection/wetting/opto cells, logic/MCU, then relay drivers.

## Differences For This ESP32 Interface Board

- The OEM board appears to include original control-board logic. This project is an operating-control interface and must preserve the OEM ignition control module; it must not add direct gas-valve drive.
- The ESP32 antenna imposes a copper/component keepout that the OEM board did not have. Put the module at a clear board edge with the antenna facing outward.
- The dual series heat-request relays should remain visibly isolated and reviewable. Do not hide the contact-chain path under dense logic routing.
- Thermistor and SFS analog inputs need a quieter zone than the photo's general-purpose digital fanout suggests. Keep those traces away from the buck converter, relay coils, and AC sense inputs.
- The field verification record still governs final connector order and assumptions. The photo supports the manual-aligned connector grouping but does not close any release gate by itself.

## Actionable Floorplan Changes

- Shift from generic placement envelopes toward an OEM-inspired left-to-right service flow:
  field connectors -> protection/sense cells -> MCU/supervisor/gates -> relay drivers/relay contacts and edge test headers.
- Keep the 24 VAC supply cluster tight in one upper corner, with explicit keepout from thermistor/SFS analog routing.
- Group `PS`, `HLS`, `ES1`, `AFS`, `AGS`, `SFS`, and `GAS` sense cells as a repeated vertical bank next to `J3`, matching the photo's readable troubleshooting pattern.
- Reserve a lower-edge debug strip for `+5V`, `+3V3`, `GND`, watchdog, `SAFETY_STATIC_OK`, relay gates/coils, `TH`, and `VAL` sense.
- Add mounting-hole and connector-service keepouts early, because the OEM board uses nearly the full width while preserving access at every edge.

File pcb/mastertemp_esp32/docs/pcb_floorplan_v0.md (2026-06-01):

# PCB Floorplan v0

Date: 2026-05-31

This is the first physical design pass for the MasterTemp ESP32 interface board. It intentionally uses board-level placement envelopes and labels rather than unsynchronized footprints, because the schematic sheets are still TODO-only. Real footprints should be added after the matching schematic symbols and part selections exist.

An OEM Pentair control-board photo was reviewed on 2026-06-01 and summarized in `oem_board_photo_layout_notes.md`. The photo supports an edge-serviceable layout with field connectors around the perimeter, repeated sense/protection cells just inside the connector edge, central control logic, a compact switching-supply island, and service/debug headers along the lower edge.

## Placement Intent

- `J1 POWER` sits at the upper-left service edge for 24 VAC Class II input.
- `J2 OPERATING CONTROL` follows the Rev C manual operating-control terminal organization: `VAL`, `TH`, `IND`, `GND`, `24VAC`, `24VAC`, `FS`.
- `J3 SAFETY STACK`, `J4 THERMISTOR`, `J5 EXT CTRL`, and `J6 MEMBRANE REF` mirror the major operating-control connector groups shown in Rev C Figure 24.
- `J6` is a reference/compatibility envelope only; keypad, membrane-pad, display, buzzer, and status-LED electronics are not part of this design scope.
- `K1` and `K2` are placed in series between the ICM connector and the logic/control regions.
- AC optocoupler sensing straddles the left-side field/logic boundary.
- The 100 V buck area is kept center-left with room for a compact switch loop.
- The ESP32 module is on the right side with its antenna aimed toward the board edge.
- `J3`, `J4`, and `J5` occupy the bottom/right service edges for safety, remote, and UI wiring.
- ADC/comparator circuitry is grouped in the lower-right logic area and kept away from the buck and relay regions.
- A test-pad row is reserved for power rails, watchdog, safety chain, relay drive, TH feedback, and VAL sense.
- An OEM ignition-control module terminal-row envelope is included as a reference for `S1/240`, `S1/120`, `L1`, `L2`, `S2`, `TH`, `IND`, `VAL`, and `GND`.

## OEM Photo-Informed Refinements

- Keep the board easy to service from the edges: heater-facing connectors should remain on perimeter edges with readable labels and enough finger/tool clearance.
- Place `J2` and `J3` next to repeated optocoupler/protection/sense cells so operating-control and safety-stack channels are visually traceable.
- Group the safety sense channels as a readable bank near `J3`: `PS`, `HLS`, `ES1`, `AFS`, `AGS`, `SFS`, and `GAS`.
- Keep relay hardware in a corner/edge zone with the `TH` contact-chain path obvious and separated from MCU, crystal, ADC, and sensor front ends.
- Keep the buck converter as a compact island with regulator, diode, inductor, and bulk capacitors close together; route thermistor and SFS signals around it, not through it.
- Put ESP32 support, watchdog, and relay-gate logic near the center/right logic region, but keep the ESP32 antenna at a clear board edge.
- Preserve a lower-edge debug/service strip for programming, rail checks, watchdog, safety-chain state, relay drive, `TH` feedback, and `VAL` sense.
- Treat UI/keypad/membrane reference connectors as perimeter compatibility features, not as core logic placement drivers.

## Release Caveats

- This is not yet a routable or fabricable electrical layout.
- Connector footprints, relay footprints, mounting holes, and exact keepouts must be replaced with real footprints after schematic capture.
- Internal isolation slots are marked as future placement targets only.
- Schematic parity is intentionally preserved by avoiding board-only footprints at this stage.
- The installed heater harness must be checked before relying on the Rev C diagram for final pin order.
- The OEM-board photo is a layout reference only and does not verify connector pin order, ratings, component values, or safety compliance.

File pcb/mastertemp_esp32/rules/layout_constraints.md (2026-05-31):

# Layout Constraints

These are human-readable constraints for the first KiCad layout pass. Convert them into KiCad board setup rules/custom DRC once the exact KiCad version is selected.

## Zones

- Zone A: 24 VAC input, fuse, MOV/TVS, bridge, bulk capacitor.
- Zone B: VRAW buck converter and hot switching loop.
- Zone C: ESP32, watchdog, ADC, I2C, logic.
- Zone D: relay contacts and ICM connector.
- Zone E: remote/UI field wiring.

## First-pass floorplan

- Board outline target: keep the existing 160 mm x 100 mm scaffold until the real enclosure and heater mounting envelope are measured.
- Left edge: place all heater/field connectors so harnesses enter from one service side.
- Top-left: place `J1_POWER`, fuse/PTC, MOV, bridge, TVS, and VRAW bulk capacitor in Zone A.
- Center-left: place `U1` 24 VAC-derived 5 V buck and its inductor/diode/input capacitors in Zone B, with the switch loop compact and away from sensor traces.
- Right side: place ESP32 module in Zone C with antenna pointed toward the nearest board edge and a no-copper/no-component keepout under and in front of the antenna.
- Bottom-left: place `J2_ICM`, `K1`, and `K2` in Zone D with the relay-contact path short, wide, and visibly separated from logic copper.
- Bottom/right edge: place `J3_SAFETY_SENSORS`, `J4_REMOTE`, and `J5_UI` in Zone E, grouped by harness function rather than by schematic page.
- Center/right: place ADC, thermistor/SFS protection, comparators, watchdog, reset supervisor, and I/O expander close to the ESP32 but outside the antenna keepout.
- Keep optocouplers straddling the field/logic boundary, with field-side pins facing connectors and logic-side pins facing ESP32/MCP23017.
- Reserve room for isolation slots between relay contacts/AC sense field wiring and SELV logic where footprints permit.

## Required separations

- No line voltage on PCB.
- Keep field wiring and logic separated by practical clearance and silkscreen boundaries.
- Add isolation slots under/near optocouplers and relay contact regions where they improve tolerance to contamination or miswire.
- Keep ESP32 antenna clear of copper, connectors, relays, transformer wiring, and enclosure metal.
- Route thermistor and SFS traces away from relay coils, buck switch nodes, AC sense inputs, and connector ESD current paths.

## Required labels

- NO LINE VOLTAGE ON CONTROL TERMINALS
- 24 VAC CLASS II CONTROL POWER ONLY
- GAS VALVE MONITOR ONLY - DO NOT DRIVE
- INSTALL/SERVICE BY QUALIFIED TECHNICIAN
- VERIFY WIRING AGAINST HEATER MANUAL BEFORE POWER

## Open mechanical inputs

- Exact enclosure internal dimensions, lid clearance, standoff locations, and cable gland/harness-entry direction.
- Exact heater control compartment mounting method and whether this board is an interposer, replacement panel board, or bench-test module.
- Connector family, pitch, wire gauge, pluggable/keyed requirements, and service-loop clearance.
- Required conformal coating, drainage/orientation constraints, and minimum contamination class for creepage decisions.

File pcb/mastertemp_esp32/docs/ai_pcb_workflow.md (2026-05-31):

# AI-Assisted KiCad Workflow

Use AI for small, reviewable PCB tasks:

1. Convert requirements into connector and sheet checklists.
2. Draft one schematic sheet at a time.
3. Generate symbol/footprint skeletons for project-local parts.
4. Review ERC/DRC JSON output and propose fixes.
5. Maintain BOM attributes and review substitutions.
6. Create fabrication and bench-test checklists.

Do not use AI output as final approval for:

- Gas-appliance safety behavior.
- Creepage/clearance around field wiring.
- Relay failure-mode assumptions.
- Certification or code compliance.
- Heater-specific harness mapping.

For this board, make the first implementation pass in this order:

1. `power_24vac`
2. `esp32_supervisor`
3. `icm_interface`
4. `safety_inputs`
5. `thermistor_sfs`
6. `ui_remote`
7. PCB outline, connector placement, and safety-zone layout
8. Routing and fabrication outputs

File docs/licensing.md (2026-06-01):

# Licensing Notes

The repository currently uses the MIT License at the root.

MIT is simple and permissive, and it covers the repository as published unless a file states otherwise. It also includes a broad warranty disclaimer, which is important for a project that is not certified and not ready for live-appliance use.

Before the first public hardware release, consider whether the KiCad hardware design files should move to a hardware-specific license such as:

- CERN Open Hardware Licence Version 2 - Strongly Reciprocal (`CERN-OHL-S-2.0`).
- CERN Open Hardware Licence Version 2 - Weakly Reciprocal (`CERN-OHL-W-2.0`).
- CERN Open Hardware Licence Version 2 - Permissive (`CERN-OHL-P-2.0`).

Do not publish release artifacts until the intended license is clear in the root README, release notes, and generated fabrication package.

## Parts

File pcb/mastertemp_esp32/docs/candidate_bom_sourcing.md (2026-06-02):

# Candidate BOM and Sourcing Notes

Date: 2026-05-31

Status: candidate engineering BOM only. These parts are placed on the draft PCB to drive mechanical and routing work. They are not procurement-approved, agency-approved, or release-approved for connection to a live heater.

## Candidate Parts

| Ref | Candidate part | Function | Footprint placed |
| --- | --- | --- | --- |
| J1 | Phoenix Contact MSTBA 2,5/3-G-5,08 family | 24 VAC input | `PhoenixContact_MSTBA_2,5_3-G-5,08_1x03_P5.08mm_Horizontal` |
| J2, J3 | Phoenix Contact MSTBA 2,5/7-G-5,08, `1757297` | Operating-control and safety-stack terminals | `PhoenixContact_MSTBA_2,5_7-G-5,08_1x07_P5.08mm_Horizontal` |
| J4 | Phoenix Contact MSTBA 2,5/2-G-5,08 family | Thermistor terminal | `PhoenixContact_MSTBA_2,5_2-G-5,08_1x02_P5.08mm_Horizontal` |
| J5 | Phoenix Contact MSTBA 2,5/3-G-5,08 family | External Pool/Common/Spa control | `PhoenixContact_MSTBA_2,5_3-G-5,08_1x03_P5.08mm_Horizontal` |
| J6 | Phoenix Contact MSTBA 2,5/9-G-5,08 family | OEM membrane connector reference only | `PhoenixContact_MSTBA_2,5_9-G-5,08_1x09_P5.08mm_Horizontal` |
| K1, K2 | Omron `G5Q-1A-DC5` candidate | Dual normally-open heat-request relays | `Relay_SPST_Omron-G5Q-1A` |
| U1 | TI `LM5164DDAR` candidate | 100 V input 5 V buck | `TI_SO-PowerPAD-8` |
| U2 | Diodes Inc. `AP63203WU-7` | 3.3 V buck | `TSOT-23-6` |
| U3 | TI `TPS3839G33DBZR` | 3.3 V reset/brownout supervisor | `SOT-23-3` |
| U4 | TI `TPS3823-33DBVR` | Watchdog supervisor | `SOT-23-5` |
| U5 | Espressif `ESP32-WROOM-32E-N16` | Controller module | `ESP32-WROOM-32E` |
| U6 | Microchip `MCP23017-E/SS` | I/O expander | `SSOP-28_5.3x10.2mm_P0.65mm` |
| U7 | TI `ADS1115IDGSR` | External ADC | `VSSOP-10_3x3mm_P0.5mm` |
| U8 | Murata `NXE1S0505MC-R7` | Isolated 5 V wetting supply | `Converter_DCDC_Murata_NXE1SxxxxMC_SMD` |
| U9-U12 | onsemi `H11AA1M` | AC optocoupler sense channels | `DIP-6_W7.62mm` |
| U14 | Thermistor AFE TBD | Thermistor divider/filter/protection placeholder | `SOT-23-6` |
| U16-U17 | TI `TLV6700DDCR` | Thermistor/SFS window comparators | `SOT-23-6` |
| U18 | TI `OPA333AIDBVR` | Optional SFS buffer | `SOT-23-5` |
| U19-U20 | LiteOn `LTV-817S` class candidate | External Pool/Spa dry-contact isolated sense | `DIP-4_W7.62mm` |
| R1-R2 | 2.2 k 0805 candidate | Remote dry-contact wetting-current limiters | `R_0805_2012Metric` |
| R3-R4 | 10 k 0805 candidate | Remote sense logic-side pullups | `R_0805_2012Metric` |
| R8-R9 | VAL optocoupler input limiters TBD | Two-part series current limiting for U11 H11AA1M AC input | `R_0805_2012Metric` |
| R13-R14 | TH optocoupler input limiters TBD | Two-part series current limiting for U9 H11AA1M AC input | `R_0805_2012Metric` |
| R16-R17 | IND optocoupler input limiters TBD | Two-part series current limiting for U10 H11AA1M AC input | `R_0805_2012Metric` |
| R19-R20 | 24 VAC optocoupler input limiters TBD | Two-part series current limiting for U12 H11AA1M AC input | `R_0805_2012Metric` |
| C2-C3 | 100 nF 0805 candidate | Remote sense debounce/filter capacitors | `C_0805_2012Metric` |
| C4 | 2.2 uF 100 V TBD | LM5164 local VRAW input bypass | `C_1210_3225Metric` |
| C5 | 2.2 nF 50 V TBD | LM5164 bootstrap capacitor | `C_0603_1608Metric` |
| R5-R6 | LM5164 feedback divider TBD | 5 V setpoint divider | `R_0805_2012Metric` |
| R7 | LM5164 RON TBD | On-time/frequency programming resistor | `R_0805_2012Metric` |
| R10-R11 | Relay MOSFET gate pulldowns TBD | Local off-state bias for K1/K2 low-side drivers | `R_0805_2012Metric` |
| R22-R23 | Relay MOSFET series-gate resistors TBD | Local drive damping/current limiting between relay-gate logic and Q1/Q2 gate nodes | `R_0805_2012Metric` |
| R24 | Thermistor pullup TBD | Water thermistor divider pullup placeholder from `+3V3_ADC` to `THERMISTOR_ADC` | `R_0805_2012Metric` |
| R25-R26 | I2C pullups TBD | SDA/SCL pullup placeholders from `+3V3` to the U6/U7 I2C bus | `R_0805_2012Metric` |
| R27 | SFS input series/protection TBD | Stack flue sensor input placeholder from `SFS_INPUT` to `SFS_FIELD_INPUT` | `R_0805_2012Metric` |
| R28-R29 | VRAW monitor divider TBD | Raw 24 VAC-derived rail monitor divider from `VRAW` to `VRAW_MONITOR_ADC` and `AGND` | `R_0805_2012Metric` |
| R30-R31 | Comparator output pullups TBD | Thermistor/SFS range comparator output pullup placeholders to `+3V3` | `R_0805_2012Metric` |
| R32-R39 | Comparator threshold dividers TBD | Thermistor/SFS low/high reference ladder placeholders from `+3V3_ADC` to `AGND` | `R_0805_2012Metric` |
| R12 | VAL optocoupler pullup TBD | Logic-side pullup for U11 collector / MCP23017 GPA0 | `R_0805_2012Metric` |
| R15 | TH optocoupler pullup TBD | Logic-side pullup for U9 collector / MCP23017 GPA1 | `R_0805_2012Metric` |
| R18 | IND optocoupler pullup TBD | Logic-side pullup for U10 collector / MCP23017 GPA2 | `R_0805_2012Metric` |
| R21 | 24 VAC optocoupler pullup TBD | Logic-side pullup for U12 collector / MCP23017 GPA3 | `R_0805_2012Metric` |
| C6 | 100 nF TBD | AP63203 bootstrap capacitor | `C_0603_1608Metric` |
| C7 | 10 uF 50 V TBD | AP63203 local +5 V input bypass | `C_1210_3225Metric` |
| C8 | 22 uF 10 V TBD | AP63203 +3V3 output capacitor | `C_0805_2012Metric` |
| C9 | Thermistor ADC filter TBD | Water thermistor ADC low-pass filter placeholder from `THERMISTOR_ADC` to `AGND` | `C_0805_2012Metric` |
| C10 | SFS ADC filter TBD | Stack flue sensor ADC low-pass filter placeholder from `SFS_ADC` to `AGND` | `C_0805_2012Metric` |
| C11 | VRAW monitor ADC filter TBD | Raw-rail monitor ADC low-pass filter placeholder from `VRAW_MONITOR_ADC` to `AGND` | `C_0805_2012Metric` |
| Q1-Q2 | `AO3400A` candidate | Relay low-side drivers | `SOT-23` |

## Source Checks

- Phoenix Contact lists `MSTBA 2,5/7-G-5,08` part `1757297` as a 7-position, 5.08 mm pitch COMBICON MSTB header rated 12 A and 320 V in the catalog context.
- Espressif's ESP32-WROOM-32E datasheet lists the `ESP32-WROOM-32E-N16` ordering code with 16 MB flash and -40 C to 85 C ambient rating.
- TI's LM5164 datasheet covers a 100 V input synchronous buck family and provides reference BOM/layout data; final values must be calculated for the selected 24 VAC transformer range.
- Diodes Inc.'s AP63203 datasheet lists `AP63203WU-7` as a fixed 3.3 V TSOT26 regulator variant.
- TI's TLV6700 datasheet lists `TLV6700DDCR` active in 6-pin SOT-23-THIN/DDC with -40 C to 125 C operation.
- DigiKey currently lists `H11AA1M` as an onsemi 6-DIP optoisolator with 4170 Vrms isolation and active stock.
- The H11AA1M schematic symbol now follows the onsemi/Fairchild pinout: pins 1-2 AC input, pin 3 NC, pin 4 emitter, pin 5 collector, pin 6 base. U11 VAL input is captured through R8/R9 placeholder series limiters to `ICM_GND_REF`; its output collector has R12 as a logic-side pullup placeholder to `+3V3`. U9 TH input is captured through R13/R14 from `TH_HEAT_REQUEST_OUT` to `ICM_GND_REF`; its output collector has R15 as a logic-side pullup placeholder to `+3V3` and connects to MCP23017 GPA1. U10 IND input is captured through R16/R17 from `IND_SENSE_AC` to `ICM_GND_REF`; its output collector has R18 as a logic-side pullup placeholder to `+3V3` and connects to MCP23017 GPA2. U12 24 VAC input is captured through R19/R20 from `ICM_24VAC_SOURCE` to `ICM_GND_REF`; its output collector has R21 as a logic-side pullup placeholder to `+3V3` and connects to MCP23017 GPA3. Final resistor values, surge/power ratings, output filtering, and sensing margin remain design items.
- R10/R11 are first-pass 0805 gate pulldown placeholders for Q1/Q2. R22/R23 are first-pass 0805 series-gate placeholders between the schematic-only relay-gate logic drive nets and the local MOSFET gate nodes. Final resistance, tolerance, leakage margin, damping, and reset behavior need relay-drive review before release.
- R24 and C9 are first-pass 0805 thermistor divider/filter placeholders. R24 ties `+3V3_ADC` to `THERMISTOR_ADC`, and C9 filters `THERMISTOR_ADC` to `AGND`; final pullup value, rail choice, filter capacitance, leakage, ADC source impedance, and fault thresholds need field curve verification before release.
- R27 and C10 are first-pass 0805 SFS conditioning placeholders. R27 reserves a series/protection element from `SFS_INPUT` to `SFS_FIELD_INPUT`, and C10 reserves an ADC-side filter from `SFS_ADC` to `AGND`. Final topology, value, leakage, clamp strategy, and whether/how `SFS_RETURN_OR_REF` is referenced remain dependent on installed SFS characterization.
- R25/R26 are first-pass 0805 I2C pullup placeholders. They tie `I2C_SDA` and `I2C_SCL` to `+3V3` near U6; final values depend on bus capacitance, selected I2C speed, device leakage, and whether any module-level pullups remain installed.
- R28/R29 and C11 are first-pass 0805 raw-rail monitor placeholders. R28 samples `VRAW` near TP1, while R29 and C11 terminate/filter `VRAW_MONITOR_ADC` in the analog cluster at `AGND`; final divider ratio, resistor voltage/power rating, leakage, filter capacitance, ADC source impedance, and firmware scaling remain design items.
- R30/R31 are first-pass 0805 pullup placeholders for `THERMISTOR_RANGE_OK` and `SFS_RANGE_OK`. Final values and whether the pullups are populated depend on the selected comparator output topology, leakage, startup behavior, and static-safety logic review.
- R32-R39 are first-pass 0805 threshold-divider placeholders for the TLV6700 thermistor and SFS window references. Final values depend on the verified water thermistor curve, installed SFS electrical behavior, TLV6700 input/common-mode limits, hysteresis strategy, tolerance stackup, leakage, ADC rail accuracy, and fault thresholds.
- The `LTV-817S` class remote-input optocoupler and R/C values are first-pass placeholders for isolated dry-contact sensing. Final CTR, wetting current, leakage, debounce, and EMC values need review.

## Checked Source Links

- Phoenix Contact `1757297`: https://www.phoenixcontact.com/en-nl/products/pcb-header-mstba-25-7-g-508-1757297
- Espressif ESP32-WROOM-32E datasheet: https://documentation.espressif.com/esp32-wroom-32e_esp32-wroom-32ue_datasheet_en.html
- TI LM5164 product page: https://www.ti.com/product/LM5164
- Omron G5Q relay family: https://components.omron.com/us-en/products/relays/G5Q
- TI ADS1115IDGSR: https://www.ti.com/product/ADS1115/part-details/ADS1115IDGSR
- Microchip MCP23017: https://www.microchip.com/en-us/product/mcp23017
- Murata NXE1S0505MC-R7 datasheet: https://www.murata.com/products/productdata/8807031865374/kdc-nxe1.pdf
- Diodes Inc. AP63203: https://www.diodes.com/part/view/AP63203/
- TI TLV6700DDCR: https://www.ti.com/product/TLV6700/part-details/TLV6700DDCR
- DigiKey/onsemi `H11AA1M`: https://www.digikey.com/en/products/detail/onsemi/H11AA1M/1053602
- LiteOn `LTV-817S` family: https://optoelectronics.liteon.com/en-global/Home/ProductDetail?partNo=LTV-817S

## Open Sourcing Items

- Confirm final relay choice with safety review. `G5Q-1A-DC5` is placed as a more robust NO relay candidate; contact-rating, coil power, agency rating, and failure-mode requirements still need approval.
- Confirm exact connector family against enclosure, wire gauge, harness strain relief, and service clearances.
- Confirm U1 package and buck compensation/reference component values against the exact TI design procedure.
- Confirm U6 MCP23017 GPIO allocation, interrupt use, I2C pullup strategy, address policy, and reset behavior before relying on the expander for any control or diagnostic functions.
- Confirm U8 isolated-supply creepage/clearance, load range, EMC filtering, and whether the isolated return should remain only `COMMON_LINE` for the external dry-contact interface.
- Confirm U9-U12 H11AA1M input current limiting, surge tolerance, CTR margin, output pullup/filtering, and whether the base pins should be tied or left open before connecting these monitors. U11 VAL, U9 TH, U10 IND, and U12 24 VAC now have first-pass resistor-chain and pullup placeholders.
- Confirm Q1/Q2 relay-drive gate network values, including R10/R11 pulldowns and R22/R23 series gate resistors, against ESP32 boot/reset states and supervisor behavior.
- Confirm the installed water thermistor curve and temperature range, then value R24/C9 and the comparator thresholds around the verified ADC source impedance and failure modes.
- Characterize the installed SFS electrical type/range before finalizing R27/C10, U18 usage, SFS return/reference handling, and U17 threshold components.
- Confirm I2C bus capacitance, firmware bus speed, and external/module pullup policy before assigning final R25/R26 values.
- Confirm the VRAW monitor divider/filter values and ratings for the expected 24 VAC transformer tolerance, rectified rail range, ADC input limits, startup behavior, leakage, and fault cases.
- Confirm U16/U17 output stage behavior and range-ok pullup values before relying on the static safety chain.
- Confirm U16/U17 low/high threshold divider values and hysteresis policy from measured thermistor/SFS curves before populating R32-R39.
- Confirm whether a certified 24 VAC to 5 V module is preferable to an onboard buck for EMC, thermal, and certification reasons.
- Confirm external-control wetting-current source, optocoupler CTR margin, leakage behavior, and both-contacts-closed fault handling before relying on the remote input circuit.

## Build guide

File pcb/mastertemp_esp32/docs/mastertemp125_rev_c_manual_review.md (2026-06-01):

# MasterTemp 125 Rev C Manual Review

Source file: `../references/manuals/mastertemp_125_installation_users_guide_english_rev_c.pdf`

PDF metadata:

- Title: `MasterTemp 125 Heater Manual (English)`
- Revision shown in footer: Rev. C, 3/2019
- Pages: 56
- PDF modified date: 2021-05-11

## Electrical Pages Reviewed

- Page 28: electrical connections and line-voltage warnings.
- Page 29: Fireman's Switch and remote control connection instructions.
- Page 30, Figure 24: heater wiring diagram, 3-wire system.
- Page 31, Figure 25: heater electrical schematic ladder diagram.

## Manual-Derived Design Facts

- The heater has line-voltage `120/240 VAC` wiring in the junction box, but this project PCB must not carry line voltage.
- The manual warns that touching any `24 VAC` control wire, including the Fireman's Switch jumper, to a `120/240 V` terminal can destroy the control board.
- The Fireman's Switch/timer connection is a `24 VAC` control-board circuit and the external contact should be rated for `24 VAC at 0.5 A`.
- The manual calls for `18 AWG` wire with insulation rated for at least `105 C` temperature rise for the Fireman's Switch wiring.
- The operating-control top terminal order shown in Figure 24 is `VAL`, `TH`, `IND`, `GND`, `24VAC`, plus a separate `24VAC` / `FS` Fireman's Switch block.
- The operating-control left safety stack shown in Figure 24 is `PS`, `HLS`, `ES1`, `AFS`, `AGS`, `SFS`, `GAS`.
- The operating-control has a separate thermistor connector pair near the top-right of the board.
- The operating-control has a right-side `J6` membrane-pad connector. This project may reference that connector for control-board compatibility, but does not design the keypad/membrane-pad assembly.
- The three-wire external-control interface shown in Figure 24 is `Spa Line`, `Common Line`, `Pool Line`.
- The ignition-control module terminal row shown in Figure 24/Figure 25 includes `S1/240`, `S1/120`, `L1`, `L2`, `S2`, `TH`, `IND`, `VAL`, and `GND`.
- The ladder diagram shows the OEM ignition-control module owns ignition, blower, gas-valve, `TH`, `IND`, `VAL`, and `GND` sequencing.

## Project Updates From This Review

- Renamed the generic draft `J2 ICM` interface to a manual-aligned `J2 OPERATING CONTROL 7P` envelope.
- Split the previous combined safety/sensor connector concept into manual-aligned envelopes:
  - `J3 SAFETY STACK 7P`
  - `J4 THERMISTOR 2P`
  - `J5 EXT CTRL 3P`
  - `J6 MEMBRANE / UI`
- Added a PCB reference envelope for the OEM ignition-control module terminal row.
- Kept `VAL` and `GAS` marked monitor-only; no board output should drive the gas valve.

## Open Verification Items

- The PDF diagrams are authoritative for the Rev C manual, but the installed heater revision and harness must still be inspected before schematic release.
- Wire colors from the PDF should be treated as service hints, not a substitute for continuity verification on the installed unit.
- The exact J6 membrane-pad pin mapping still needs harness-level verification.

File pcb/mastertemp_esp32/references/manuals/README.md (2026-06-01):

# Reference Manuals

Keep project-local manual and source-document copies here.

Current files:

- `mastertemp_125_installation_users_guide_english_rev_c.pdf`: Pentair MasterTemp 125 Installation and Users Guide, English, Rev. C, P/N 475000 Rev. C 3/2019.

When adding manuals or datasheets, prefer stable filenames with lowercase words separated by underscores. Record the source URL, revision, and review notes in `../../docs/`.

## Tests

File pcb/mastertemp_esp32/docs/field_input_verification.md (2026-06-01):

# Field Input Verification

Status: manual-assumed, field-open release gate. Values below are seeded from the included `../references/manuals/mastertemp_125_installation_users_guide_english_rev_c.pdf`, P/N 475000 Rev. C 3/2019. Do not mark the related README checklist items complete until the installed heater data below is measured, photographed where practical, and reviewed against the matching manual revision.

## Heater Identity

| Item | Recorded value | Evidence | Review status |
| --- | --- | --- | --- |
| MasterTemp 125 model number | MasterTemp 125, exact fuel/variant TBD | Manual applies to all MasterTemp 125 heater models; nameplate photo required | Manual assumed; field open |
| Serial number/date range | TBD | Nameplate photo required | Open |
| Connected or non-connected variant | TBD | Control-board/parts photo required | Open |
| Installed control board part number | `42002-0007S` appears in Rev. C replacement-parts table, exact installed part TBD | Board label/photo required | Manual reference only; field open |
| Installed ICM part number | `42001-0052S` appears in Rev. C replacement-parts table, exact installed part TBD | Module label/photo required | Manual reference only; field open |
| Manual revision matched to unit | Rev. C, 3/2019 assumed | Included PDF footer and cover show P/N 475000 Rev. C 3/2019; confirm against unit documents | Manual assumed; field open |

## Harness And Connector Verification

| Connector/group | Expected reference | Field verification required | Review status |
| --- | --- | --- | --- |
| Operating-control terminals | Rev. C Figure 24: `VAL`, `TH`, `IND`, `GND`, `24VAC`, `24VAC`, `FS` | Photograph terminal block and verify conductor order/colors | Manual assumed; field open |
| Safety stack | Rev. C Figure 24: `PS`, `HLS`, `ES1`, `AFS`, `AGS`, `SFS`, `GAS` | Photograph terminal block and verify conductor order/colors | Manual assumed; field open |
| Thermistor | Rev. C Figure 24 shows separate thermistor connector pair near operating control | Verify connector style, wire colors, and resistance at known water temperature | Manual assumed; field open |
| External control | Rev. C Figure 24: `Spa Line`, `Common Line`, `Pool Line` | Verify connector style and absence/presence of external controller wiring | Manual assumed; field open |
| Fireman's Switch | Rev. C text states the controller/timer/relay completes a 24 VAC control-board circuit and should be rated 24 VAC at 0.5 A | Verify wiring and confirm no line voltage is present | Manual assumed; field open |

## Electrical Measurements

Use an isolated meter and a qualified technician. Record meter model, measurement conditions, and whether the heater was idle, calling for heat, or firing.

| Measurement | Condition | Recorded value | Acceptance/review note | Review status |
| --- | --- | --- | --- | --- |
| 24 VAC transformer secondary | No-load | 24 VAC nominal Class II transformer assumed; no-load voltage TBD | Size `VRAW` and surge margin from measured high line/unloaded behavior | Manual assumed; field open |
| 24 VAC transformer secondary | Loaded/idle control powered | 24 VAC nominal assumed; loaded value TBD | Confirm supply design margin | Manual assumed; field open |
| 24 VAC transformer secondary | Heat call active | 24 VAC nominal assumed; active value TBD | Confirm relay/contact and sense design assumptions | Manual assumed; field open |
| `TH` to `GND` | Immediately after heat request | 24 VAC expected per troubleshooting flow; measured value TBD | Manual troubleshooting expects 24 VAC behavior | Manual assumed; field open |
| `VAL`/gas-valve monitor | Ignition trial only | 24 VAC expected during ignition try; measured value TBD | Sense-only validation; no drive allowed | Manual assumed; field open |
| Fireman's Switch current/voltage | Closed and open states | 24 VAC at up to 0.5 A control circuit assumed; measured value TBD | Confirm low-voltage control-only interface | Manual assumed; field open |

## Sensor Characterization

| Sensor | Field data required | Recorded value | Review status |
| --- | --- | --- | --- |
| Water thermistor | Resistance at known water temperature; open/short behavior if safely simulated | Manual shows thermistor sensor and diagnostic LED; curve TBD | Manual assumed; field open |
| Stack flue sensor | Electrical type, normal range, fault range, and harness behavior | Manual states SFS shuts down heater at 480 F / 249 C; electrical type/range TBD | Manual assumed; field open |
| AFS | Idle state and proven-airflow state timing relative to blower/`IND` | Manual states AFS closes after sufficient airflow; timing TBD | Manual assumed; field open |
| PS/HLS/AGS/ES1 | Normal closed/open behavior and installed jumper state where applicable | Manual states PS proves pump, HLS opens above 135 F / 57 C, AGS opens above 140 F / 60 C; ES1 jumper/use TBD | Manual assumed; field open |

## Mechanical Inputs

| Item | Recorded value | Review status |
| --- | --- | --- |
| Enclosure selection | TBD | Open |
| Mounting-hole pattern | TBD | Open |
| Standoff height | TBD | Open |
| Cable-entry direction | TBD | Open |
| Service clearance | TBD | Open |
| Environmental exposure assumptions | TBD | Open |

## Certification And Review Path

| Item | Recorded value | Review status |
| --- | --- | --- |
| Qualified technician reviewer | TBD | Open |
| Controls/electrical safety reviewer | TBD | Open |
| Applicable standards/review basis | TBD | Open |
| FMEA owner and review date | TBD | Open |
| Bench-test approval before live-heater connection | TBD | Open |

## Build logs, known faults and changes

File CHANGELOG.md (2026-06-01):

# Changelog

This project uses a lightweight changelog until formal releases begin.

## Unreleased

- Added GitHub community documentation for open-source contribution.
- Added first-pass KiCad scaffold, design notes, requirements, scripts, and tests.
- Added manual-assumed field verification record and OEM board photo layout notes.

No installable hardware release has been made.

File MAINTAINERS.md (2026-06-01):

# Maintainers

This project is currently maintained by the repository owner.

Maintainers should be able to review:

- KiCad schematic and PCB changes.
- Embedded-control safety boundaries.
- Gas-appliance interface risks.
- Test and release-gate documentation.

## Review Ownership

- Documentation-only changes: normal maintainer review.
- Schematic or PCB changes: maintainer review plus checks.
- Heat-request, relay, safety-input, watchdog, brownout, thermistor/SFS, or live-test changes: explicit safety review before merge.
- Public release artifacts: maintainer approval after checklist review.

Add named maintainers here when the GitHub repository has stable owners.

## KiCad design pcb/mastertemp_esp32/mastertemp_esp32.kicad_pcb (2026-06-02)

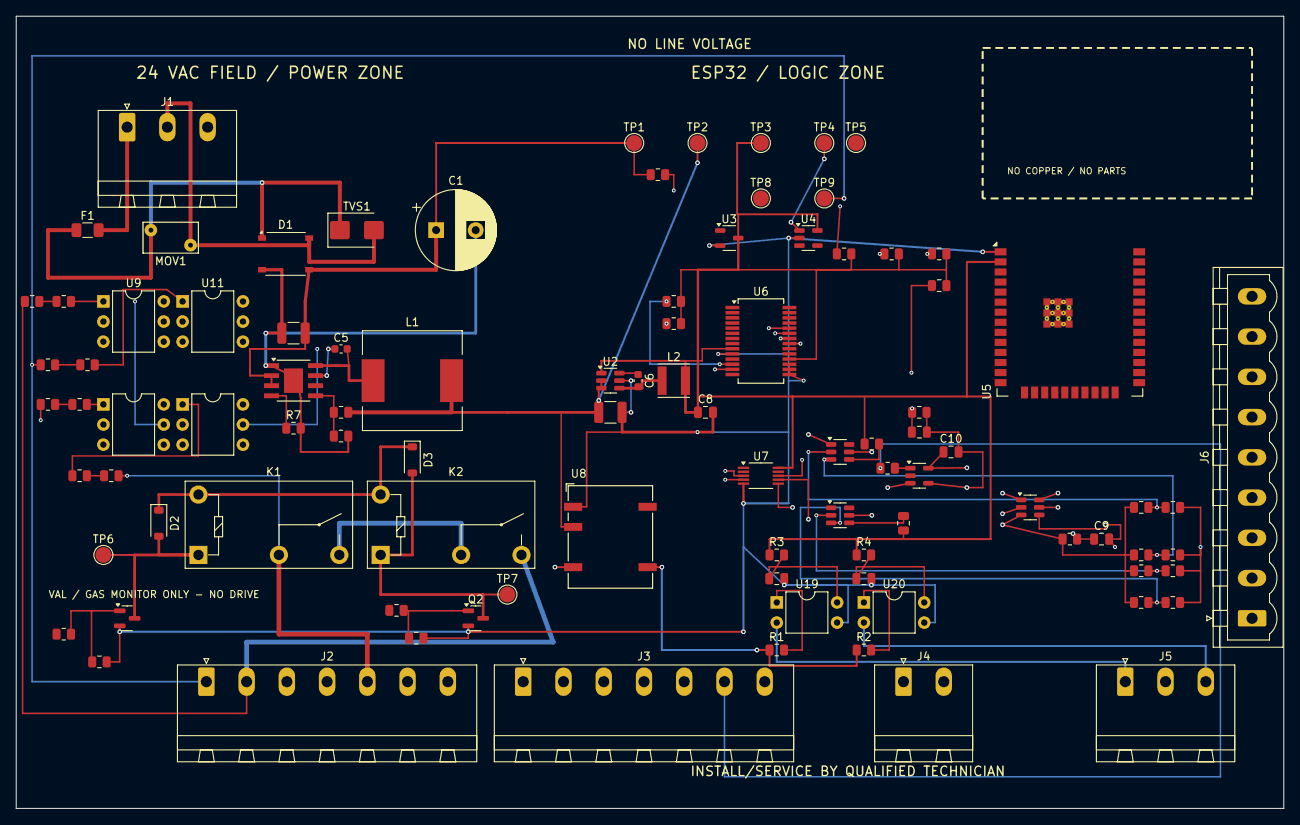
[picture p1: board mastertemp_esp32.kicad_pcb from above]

Board: 4 copper layers, 160.0 x 100.0 mm, 95 parts (0 on the bottom side), 64 nets.

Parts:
C1: 470uF_63V; CP_Radial_D10.0mm_P5.00mm
C2, C3: 100nF_REMOTE_FILTER_TBD; C_0805_2012Metric
C4: 2.2uF_100V_VRAW_IN_TBD; C_1210_3225Metric
C5: 2.2nF_50V_BST_5V; C_0603_1608Metric
C6: 100nF_BST_3V3; C_0603_1608Metric
C7: 10uF_50V_3V3_IN_TBD; C_1210_3225Metric
C8: 22uF_10V_3V3_OUT_TBD; C_0805_2012Metric
C9: THERM_ADC_FILTER_TBD; C_0805_2012Metric
C10: SFS_ADC_FILTER_TBD; C_0805_2012Metric
C11: VRAW_MON_FILTER_TBD; C_0805_2012Metric
D1: MB10S; Diode_Bridge_Vishay_MBLS
D2: K1_FLYBACK_TBD; D_SOD-123
D3: K2_FLYBACK_TBD; D_SOD-123
F1: 0.5A_FUSE; Fuse_1206_3216Metric
J1: 24VAC_IN; PhoenixContact_MSTBA_2,5_3-G-5,08_1x03_P5.08mm_Horizontal
J2: OPERATING_CONTROL; PhoenixContact_MSTBA_2,5_7-G-5,08_1x07_P5.08mm_Horizontal
J3: SAFETY_STACK; PhoenixContact_MSTBA_2,5_7-G-5,08_1x07_P5.08mm_Horizontal
J4: THERMISTOR; PhoenixContact_MSTBA_2,5_2-G-5,08_1x02_P5.08mm_Horizontal
J5: EXT_CONTROL; PhoenixContact_MSTBA_2,5_3-G-5,08_1x03_P5.08mm_Horizontal
J6: MEMBRANE_REF; PhoenixContact_MSTBVA_2,5_9-G-5,08_1x09_P5.08mm_Vertical
K1, K2: G5Q-1A-DC5; Relay_SPST_Omron-G5Q-1A
L1: 68uH; L_12x12mm_H8mm
L2: 2.2uH; L_Vishay_IFSC-1515AH_4x4x1.8mm
MOV1: V47ZA1P; RV_Disc_D7mm_W3.9mm_P5mm
Q1, Q2: AO3400A; SOT-23
R1, R2: 2.2k_REMOTE_WET_TBD; R_0805_2012Metric
R3, R4: 10k_REMOTE_PULLUP; R_0805_2012Metric
R5: RFB5V_TOP_TBD; R_0805_2012Metric
R6: RFB5V_BOT_TBD; R_0805_2012Metric
R7: RON5V_TBD; R_0805_2012Metric
R8: VAL_OPTO_LIMIT_A_TBD; R_0805_2012Metric
R9: VAL_OPTO_LIMIT_B_TBD; R_0805_2012Metric
R10: K1_GATE_PULLDOWN_TBD; R_0805_2012Metric
R11: K2_GATE_PULLDOWN_TBD; R_0805_2012Metric
R12: VAL_OPTO_PULLUP_TBD; R_0805_2012Metric
R13: TH_OPTO_LIMIT_A_TBD; R_0805_2012Metric
R14: TH_OPTO_LIMIT_B_TBD; R_0805_2012Metric
R15: TH_OPTO_PULLUP_TBD; R_0805_2012Metric
R16: IND_OPTO_LIMIT_A_TBD; R_0805_2012Metric
R17: IND_OPTO_LIMIT_B_TBD; R_0805_2012Metric
R18: IND_OPTO_PULLUP_TBD; R_0805_2012Metric
R19: VAC24_OPTO_LIMIT_A_TBD; R_0805_2012Metric
R20: VAC24_OPTO_LIMIT_B_TBD; R_0805_2012Metric
R21: VAC24_OPTO_PULLUP_TBD; R_0805_2012Metric
R22: K1_GATE_SERIES_TBD; R_0805_2012Metric
R23: K2_GATE_SERIES_TBD; R_0805_2012Metric
R24: THERM_PULLUP_TBD; R_0805_2012Metric
R25: I2C_SDA_PULLUP_TBD; R_0805_2012Metric
R26: I2C_SCL_PULLUP_TBD; R_0805_2012Metric
R27: SFS_INPUT_SERIES_TBD; R_0805_2012Metric
R28: VRAW_MON_TOP_TBD; R_0805_2012Metric
R29: VRAW_MON_BOT_TBD; R_0805_2012Metric
R30: THERM_RANGE_OK_PULLUP_TBD; R_0805_2012Metric
R31: SFS_RANGE_OK_PULLUP_TBD; R_0805_2012Metric
R32: THERM_LOW_REF_TOP_TBD; R_0805_2012Metric
R33: THERM_LOW_REF_BOT_TBD; R_0805_2012Metric
R34: THERM_HIGH_REF_TOP_TBD; R_0805_2012Metric
R35: THERM_HIGH_REF_BOT_TBD; R_0805_2012Metric
R36: SFS_LOW_REF_TOP_TBD; R_0805_2012Metric
R37: SFS_LOW_REF_BOT_TBD; R_0805_2012Metric
R38: SFS_HIGH_REF_TOP_TBD; R_0805_2012Metric
R39: SFS_HIGH_REF_BOT_TBD; R_0805_2012Metric
TP1: VRAW; TestPoint_Pad_D2.0mm
TP2: +5V; TestPoint_Pad_D2.0mm
TP3: +3V3; TestPoint_Pad_D2.0mm
TP4: WATCHDOG_OK; TestPoint_Pad_D2.0mm
TP5: SAFETY_STATIC_OK; TestPoint_Pad_D2.0mm
TP6: K1_COIL; TestPoint_Pad_D2.0mm
TP7: K2_COIL; TestPoint_Pad_D2.0mm
TP8: TH_FEEDBACK; TestPoint_Pad_D2.0mm
TP9: VAL_SENSE; TestPoint_Pad_D2.0mm
TVS1: SMBJ51CA; D_SMB
U1: LM5164DDAR; TI_SO-PowerPAD-8
U2: AP63203WU-7; TSOT-23-6
U3: TPS3839G33DBZR; SOT-23-3
U4: TPS3823-33DBVR; SOT-23-5
U5: ESP32-WROOM-32E-N16; ESP32-WROOM-32E
U6: MCP23017-E/SS; SSOP-28_5.3x10.2mm_P0.65mm
U7: ADS1115IDGSR; VSSOP-10_3x3mm_P0.5mm
U8: NXE1S0505MC-R7; Converter_DCDC_Murata_NXExSxxxxMC_SMD
U9: H11AA1M_TH; DIP-6_W7.62mm
U10: H11AA1M_IND; DIP-6_W7.62mm
U11: H11AA1M_VAL; DIP-6_W7.62mm
U12: H11AA1M_24VAC; DIP-6_W7.62mm
U14: THERMISTOR_AFE_TBD; SOT-23-6
U16: TLV6700DDCR_THERM; SOT-23-6
U17: TLV6700DDCR_SFS; SOT-23-6
U18: OPA333AIDBVR; SOT-23-5
U19: LTV-817S_SPA_CANDIDATE; DIP-4_W7.62mm
U20: LTV-817S_POOL_CANDIDATE; DIP-4_W7.62mm

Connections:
+3V3: C8.1, L2.2, R3.1, R4.1, R12.2, R15.2, R18.2, R21.2, R25.1, R26.1, R30.1, R31.1, TP3.1, U2.1, U3.3, U4.5, U5.2, U6.9, U6.18, U7.10
+3V3_ADC: R24.1, R32.1, R34.1, R36.1, R38.1, U14.3, U18.3
+5V: C7.1, L1.2, R5.1, TP2.1, U2.2, U2.3, U8.3
+5V_RELAY: D2.1, D3.1, K1.5, K2.5
AGND: C9.2, C10.2, C11.2, R29.2, R33.2, R35.2, R37.2, R39.2, U14.4, U18.4
BST_3V3: C6.1, U2.6
BST_5V: C5.1, U1.7
COMMON_LINE: J5.2, U8.7
FB_5V_TBD: R5.2, R6.1, U1.5
GND: C2.2, C3.2, C7.2, C8.2, Q1.2, Q2.2, R10.2, R11.2, U2.5, U3.2, U4.2, U5.1, U6.10, U6.15, U6.16, U6.17, U7.5, U8.1, U9.4, U10.4, U11.4, U12.4, U16.5, U17.5, U19.3, U20.3
HEAT_CHAIN_K1_K2: K1.3, K2.2
I2C_SCL: R26.2, U6.12, U7.4
I2C_SDA: R25.2, U6.13, U7.3
ICM_24VAC_SOURCE: J2.5, K1.2, R19.1
ICM_GND_REF: J2.4, U9.2, U10.2, U11.2, U12.2
IND_OPTO_GPIO: R18.1, U6.23, U10.5
IND_OPTO_INPUT: R17.2, U10.1
IND_OPTO_LIMIT_A: R16.2, R17.1
IND_SENSE_AC: J2.3, R16.1
ISO_REMOTE_5V: R1.1, R2.1, U8.8
K1_COIL_LOW: D2.2, K1.1, Q1.3, TP6.1
K2_COIL_LOW: D3.2, K2.1, Q2.3, TP7.1
PGND_RAW: C1.2, C4.2, D1.4, R6.2, R7.2, U1.1, U1.9
POOL_LED_A: R2.2, U20.1
POOL_LINE: J5.3, U20.2
RELAY_K1_GATE: Q1.1, R10.1, R22.2
RELAY_K2_GATE: Q2.1, R11.1, R23.2
REMOTE_POOL_SENSE: C3.1, R4.2, U20.4
REMOTE_SPA_SENSE: C2.1, R3.2, U19.4
RON_5V_TBD: R7.1, U1.4
SFS_ADC: C10.1, U7.7, U18.5
SFS_FIELD_INPUT: R27.2, U18.1
SFS_HIGH_REF_TBD: R38.2, R39.1, U17.3
SFS_INPUT: J3.6, R27.1
SFS_LOW_REF_TBD: R36.2, R37.1, U17.2
SFS_RANGE_OK: R31.2, U17.4
SPA_LED_A: R1.2, U19.1
SPA_LINE: J5.1, U19.2
SW_3V3: C6.2, L2.1, U2.4
SW_5V: C5.2, L1.1, U1.8
THERMISTOR_A: J4.1, U14.1
THERMISTOR_ADC: C9.1, R24.2, U7.6, U14.5
THERMISTOR_B: J4.2, U14.2
THERMISTOR_RANGE_OK: R30.2, U16.4
THERM_HIGH_REF_TBD: R34.2, R35.1, U16.3
THERM_LOW_REF_TBD: R32.2, R33.1, U16.2
THERM_WINDOW_SENSE: U14.6, U16.1
TH_HEAT_REQUEST_OUT: J2.2, K2.3, R13.1
TH_OPTO_GPIO: R15.1, U6.22, U9.5
TH_OPTO_INPUT: R14.2, U9.1
TH_OPTO_LIMIT_A: R13.2, R14.1
VAC24_A: F1.2, J1.1
VAC24_A_FUSED: D1.1, F1.1, MOV1.1, TVS1.1
VAC24_B: D1.2, J1.2, MOV1.2, TVS1.2
VAC24_OPTO_GPIO: R21.1, U6.24, U12.5
VAC24_OPTO_INPUT: R20.2, U12.1
VAC24_OPTO_LIMIT_A: R19.2, R20.1
VAL_OPTO_GPIO: R12.1, U6.21, U11.5
VAL_OPTO_INPUT: R9.2, U11.1
VAL_OPTO_LIMIT_A: R8.2, R9.1
VAL_SENSE_AC: J2.1, R8.1, TP9.1
VRAW: C1.1, C4.1, D1.3, R28.1, TP1.1, U1.2, U1.3
VRAW_MONITOR_ADC: C11.1, R28.2, R29.1, U7.8
WATCHDOG_OK: TP4.1, U4.1

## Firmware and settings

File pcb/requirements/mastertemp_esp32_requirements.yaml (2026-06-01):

project:
  name: mastertemp_esp32
  description: ESP32 interface board scaffold for Pentair MasterTemp 125 operating-control replacement/interposer.
  status: preliminary_not_certified
  source_design_doc: ../../MasterTemp_ESP32_Interface_Preliminary_Design.md

safety_boundary:
  classification: operating_control_interface_only
  preserve_oem_ignition_control_module: true
  direct_gas_valve_drive_allowed: false
  line_voltage_on_pcb_allowed: false
  heat_request_output:
    signal: ICM_TH_OUT
    method: isolated_series_normally_open_relay_contacts
    relay_count: 2
    fail_safe_state: open
  must_open_heat_request_on:
    - esp32_not_booted
    - esp32_watchdog_timeout
    - firmware_crash
    - three_v3_brownout
    - five_v_fault
    - invalid_thermistor
    - invalid_sfs
    - overtemperature
    - static_safety_open
    - fireman_switch_open
    - pool_spa_conflict
    - relay_feedback_fault
    - ota_in_progress

kicad:
  project_file: ../mastertemp_esp32/mastertemp_esp32.kicad_pro
  root_schematic: ../mastertemp_esp32/mastertemp_esp32.kicad_sch
  board_file: ../mastertemp_esp32/mastertemp_esp32.kicad_pcb
  preferred_board_stackup:
    layers: 4
    copper:
      - F.Cu_signal
      - In1.Cu_ground
      - In2.Cu_power
      - B.Cu_signal

hierarchical_sheets:
  - file: sheets/power_24vac.kicad_sch
    purpose: 24 VAC protection, bridge, VRAW, 5 V buck, 3.3 V regulator, brownout.
  - file: sheets/esp32_supervisor.kicad_sch
    purpose: ESP32 module, programming header, watchdog, reset supervisor, relay-enable gates.
  - file: sheets/safety_inputs.kicad_sch
    purpose: PS, HLS, ES1, AFS, AGS, Fireman's Switch, isolated sense, static safety chain.
  - file: sheets/thermistor_sfs.kicad_sch
    purpose: Water thermistor, stack flue sensor, ADC, hardware window comparators.
  - file: sheets/icm_interface.kicad_sch
    purpose: TH relay output, TH/IND/VAL/24VAC isolated monitoring, relay feedback.
  - file: sheets/ui_remote.kicad_sch
    purpose: Pool/Spa/Common external-control dry contacts only; keypad/display/buzzer design is out of scope.

net_classes:
  - name: DEFAULT
    clearance_mm: 0.20
    track_width_mm: 0.25
    notes: General low-voltage logic after review.
  - name: CONTROL_24VAC
    clearance_mm: 1.00
    track_width_mm: 0.50
    notes: 24 VAC control wiring and opto input field side.
  - name: RELAY_CONTACT_24VAC
    clearance_mm: 1.50
    track_width_mm: 1.00
    notes: Dual relay contact path for ICM TH heat request only.
  - name: VRAW_RECTIFIED
    clearance_mm: 0.80
    track_width_mm: 0.75
    notes: Rectified transformer rail, design for unloaded transformer transients.
  - name: SENSOR_ADC
    clearance_mm: 0.30
    track_width_mm: 0.20
    notes: Thermistor/SFS low-noise analog routing, away from buck and relays.
  - name: WIFI_ANTENNA_KEEPOUT
    clearance_mm: 0.00
    track_width_mm: 0.00
    notes: Region/constraint, not a routed net class.

connectors:
  J1_POWER:
    pins:
      1: 24VAC_IN_1
      2: 24VAC_IN_2
      3: CHASSIS_SHIELD
  J2_OPERATING_CONTROL:
    notes: Manual Rev C Figure 24 operating-control top terminals, left-to-right.
    pins:
      1: ICM_VAL_SENSE_MONITOR_ONLY
      2: ICM_TH_OUT
      3: ICM_IND_SENSE
      4: ICM_GND_REF
      5: ICM_24VAC_SOURCE
      6: FIREMAN_24VAC
      7: FIREMAN_SWITCH_RETURN
  J3_SAFETY_STACK:
    notes: Manual Rev C Figure 24 operating-control left safety stack order.
    pins:
      1: PS
      2: HLS
      3: ES1
      4: AFS
      5: AGS
      6: SFS
      7: GAS_MONITOR_ONLY
  J4_THERMISTOR:
    pins:
      1: THERM_A
      2: THERM_B
  J5_EXTERNAL_CONTROL:
    notes: Manual Rev C Figure 24 three-wire external control interface.
    pins:
      1: SPA_LINE
      2: COMMON_LINE
      3: POOL_LINE
  J6_MEMBRANE_REFERENCE:
    notes: Manual Rev C Figure 24 J6 membrane-pad connector reference only; this project does not design the keypad, display, buzzer, or status LED assembly.
    pins:
      1: OEM_MEMBRANE_PIN_1_VERIFY
      2: OEM_MEMBRANE_PIN_2_VERIFY
      3: OEM_MEMBRANE_PIN_3_VERIFY
      4: OEM_MEMBRANE_PIN_4_VERIFY
      5: OEM_MEMBRANE_PIN_5_VERIFY
      6: OEM_MEMBRANE_PIN_6_VERIFY
      7: OEM_MEMBRANE_PIN_7_VERIFY
      8: OEM_MEMBRANE_PIN_8_VERIFY
      9: OEM_MEMBRANE_PIN_9_VERIFY

review_gates:
  before_schematic_capture:
    - confirm_exact_heater_revision_and_harness_pinout
    - confirm_transformer_secondary_voltage_no_load_and_loaded
    - confirm_thermistor_curve_and_sfs_electrical_type
    - decide_replacement_pcba_vs_interposer
  before_layout_release:
    - complete_erc_zero_unreviewed_errors
    - complete_fmea
    - verify_relay_contact_strategy_with_certification_path
    - verify_creepage_clearance_and_miswire_tolerance
  before_heater_connection:
    - bench_test_with_isolated_24vac_transformer
    - verify_heat_request_opens_on_all_faults
    - qualified_technician_review

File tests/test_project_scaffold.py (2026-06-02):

import json
import re
import shutil
import subprocess
import unittest
from pathlib import Path


REPO_ROOT = Path(__file__).resolve().parents[1]
PROJECT_DIR = REPO_ROOT / "pcb" / "mastertemp_esp32"
ROOT_SCH = PROJECT_DIR / "mastertemp_esp32.kicad_sch"
BOARD = PROJECT_DIR / "mastertemp_esp32.kicad_pcb"
REQUIREMENTS = REPO_ROOT / "pcb" / "requirements" / "mastertemp_esp32_requirements.yaml"
DESIGN_DOC = REPO_ROOT / "MasterTemp_ESP32_Interface_Preliminary_Design.md"
PROJECT_README = PROJECT_DIR / "README.md"


class ProjectScaffoldTests(unittest.TestCase):
    def test_root_schematic_references_expected_child_sheets(self):
        text = ROOT_SCH.read_text(encoding="utf-8")
        expected_sheets = {
            "sheets/power_24vac.kicad_sch",
            "sheets/esp32_supervisor.kicad_sch",
            "sheets/icm_interface.kicad_sch",
            "sheets/safety_inputs.kicad_sch",
            "sheets/thermistor_sfs.kicad_sch",
            "sheets/ui_remote.kicad_sch",
        }

        for sheet in expected_sheets:
            self.assertIn(sheet, text)
            self.assertTrue((PROJECT_DIR / sheet).exists(), f"Missing child sheet: {sheet}")

    def test_safety_boundary_is_documented_consistently(self):
        design_doc = DESIGN_DOC.read_text(encoding="utf-8")
        requirements = REQUIREMENTS.read_text(encoding="utf-8")
        readme = PROJECT_README.read_text(encoding="utf-8")
        combined = "\n".join([design_doc, requirements, readme]).lower()

        required_phrases = [
            "no line voltage",
            "preserve the oem ignition control module",
            "two normally-open relay contacts",
            "fireman's switch",
            "watchdog",
            "brownout",
        ]

        for phrase in required_phrases:
            self.assertIn(phrase, combined)

        self.assertIn("gas valve", combined)
        self.assertIn("directly drive", combined)

    def test_requirements_keep_gas_valve_drive_disallowed(self):
        requirements = REQUIREMENTS.read_text(encoding="utf-8")

        self.assertRegex(requirements, r"direct_gas_valve_drive_allowed:\s*false")
        self.assertRegex(requirements, r"line_voltage_on_pcb_allowed:\s*false")
        self.assertRegex(requirements, r"relay_count:\s*2")
        self.assertRegex(requirements, r"fail_safe_state:\s*open")

    def test_board_has_expected_stackup_and_warning_labels(self):
        board = BOARD.read_text(encoding="utf-8")

        for layer in ["F.Cu", "In1.Cu", "In2.Cu", "B.Cu"]:
            self.assertIn(layer, board)

        required_labels = [
            "NO LINE VOLTAGE ON CONTROL TERMINALS",
            "24 VAC FIELD / POWER ZONE",
            "ESP32 / LOGIC ZONE",
            "ICM TH RELAY CONTACT ZONE",
            "ESP32 ANTENNA KEEPOUT",
        ]

        for label in required_labels:
            self.assertIn(label, board)

    def test_board_floorplan_v0_has_major_placement_envelopes(self):
        board = BOARD.read_text(encoding="utf-8")

        required_labels = [
            "J1 POWER 3P",
            "J2 OPERATING CONTROL 7P",
            "VAL TH IND GND 24VAC 24VAC FS",
            "J3 SAFETY STACK 7P",
            "PS HLS ES1 AFS AGS SFS GAS",
            "J4 THERM",
            "J5 EXT CTRL 3P",
            "SPA COMMON POOL",
            "J6 MEMBRANE REF 9P",
            "KEYPAD OUT OF SCOPE",
            "J6 SERVICE UART",
            "K1\\nNO RELAY",
            "K2\\nNO RELAY",
            "ICM REF\\nS1/240 S1/120 L1 L2 S2 TH IND VAL GND",
            "VAL / GAS MONITOR ONLY - NO DRIVE",
            "U1/L1 100 V BUCK",
            "U5 ESP32-WROOM",
            "TP ROW: VRAW +5V +3V3 WDG SAFETY K1 K2 TH VAL",
            "FUTURE ISOLATION SLOT",
        ]

        for label in required_labels:
            self.assertIn(label, board)

        floorplan_doc = PROJECT_DIR / "docs" / "pcb_floorplan_v0.md"
        self.assertTrue(floorplan_doc.exists())

    def test_manual_review_notes_exist(self):
        manual_review = PROJECT_DIR / "docs" / "mastertemp125_rev_c_manual_review.md"
        text = manual_review.read_text(encoding="utf-8")

        required_phrases = [
            "Rev. C, 3/2019",
            "Figure 24",
            "VAL`, `TH`, `IND`, `GND`, `24VAC`",
            "`PS`, `HLS`, `ES1`, `AFS`, `AGS`, `SFS`, `GAS`",
            "`Spa Line`, `Common Line`, `Pool Line`",
            "`24 VAC at 0.5 A`",
        ]

        for phrase in required_phrases:
            self.assertIn(phrase, text)

    def test_board_outline_is_160_by_100_mm_scaffold(self):
        board = BOARD.read_text(encoding="utf-8")
        self.assertIn('(layer "Edge.Cuts")', board)
        self.assertRegex(board, r"\(start\s+20\s+20\)")
        self.assertRegex(board, r"\(end\s+180\s+120\)")

    def test_completion_checklist_exists_in_project_readme(self):
        readme = PROJECT_README.read_text(encoding="utf-8")

        self.assertIn("## Completion checklist", readme)
        self.assertIn("### Schematic capture", readme)
        self.assertIn("### Safety review", readme)
        self.assertIn("### PCB layout", readme)

    def test_control_board_scope_excludes_keypad_design(self):
        requirements = REQUIREMENTS.read_text(encoding="utf-8")
        ui_sheet = (PROJECT_DIR / "sheets" / "ui_remote.kicad_sch").read_text(encoding="utf-8")
        readme = PROJECT_README.read_text(encoding="utf-8")

        combined = "\n".join([requirements, ui_sheet, readme]).lower()
        self.assertIn("keypad", combined)
        self.assertIn("out of scope", combined)
        self.assertIn("external-control dry contacts only", combined)
        self.assertNotIn("status led design is in scope", combined)

    def test_ui_remote_sheet_captures_external_control_connector(self):
        ui_sheet = (PROJECT_DIR / "sheets" / "ui_remote.kicad_sch").read_text(encoding="utf-8")

        required_phrases = [
            'lib_id "mastertemp_esp32:ExternalControl_3P"',
            'Reference" "J5"',
            'Value" "EXT_CONTROL"',
            "SPA_LINE",
            "COMMON_LINE",
            "POOL_LINE",
            'Reference" "U19"',
            'Reference" "U20"',
            "REMOTE_SPA_SENSE",
            "REMOTE_POOL_SENSE",
            "ISO_REMOTE_5V",
            'lib_id "mastertemp_esp32:MembraneReference_9P"',
            'Reference" "J6"',
            'Value" "MEMBRANE_REF"',
            "no keypad/display electronics designed",
        ]

        for phrase in required_phrases:
            self.assertIn(phrase, ui_sheet)

    def test_control_board_schematic_pass_notes_exist(self):
        icm_sheet = (PROJECT_DIR / "sheets" / "icm_interface.kicad_sch").read_text(encoding="utf-8")
        safety_sheet = (PROJECT_DIR / "sheets" / "safety_inputs.kicad_sch").read_text(encoding="utf-8")

        self.assertIn("J2 OPERATING CONTROL TERMINALS", icm_sheet)
        self.assertIn("ICM_24VAC_SOURCE -> K1_COM -> K1_NO -> K2_COM -> K2_NO -> TH_HEAT_REQUEST_OUT", icm_sheet)
        self.assertIn("VAL and GAS are diagnostic monitor inputs only", icm_sheet)
        self.assertIn('lib_id "mastertemp_esp32:H11AA1M"', icm_sheet)
        self.assertIn("AC_IN_1", icm_sheet)
        self.assertIn("COLLECTOR", icm_sheet)
        self.assertIn("J3 SAFETY STACK TERMINALS", safety_sheet)
        self.assertIn("STATIC HEAT ENABLE CHAIN", safety_sheet)
        self.assertIn("AFS DYNAMIC POLICY", safety_sheet)

    def test_candidate_parts_are_placed_on_pcb(self):
        board = BOARD.read_text(encoding="utf-8")
        required_refs = [
            "J1", "J2", "J3", "J4", "J5", "J6",
            "K1", "K2", "D2", "D3",
            "U1", "U2", "U3", "U4", "U5", "U6", "U7", "U8",
            "U9", "U10", "U11", "U12", "U14", "U16", "U17", "U18",
            "U19", "U20",
            "R1", "R2", "R3", "R4", "R5", "R6", "R7", "R8", "R9", "R10", "R11", "R12",
            "R13", "R14", "R15", "R16", "R17", "R18", "R19", "R20", "R21", "R22", "R23", "R24", "R25", "R26", "R27", "R28", "R29", "R30", "R31",
            "R32", "R33", "R34", "R35", "R36", "R37", "R38", "R39",
            "C2", "C3", "C4", "C5", "C6", "C7", "C8", "C9", "C10", "C11",
            "Q1", "Q2",
            "TP1", "TP2", "TP3", "TP4", "TP5", "TP6", "TP7", "TP8", "TP9",
        ]

        for ref in required_refs:
            self.assertIn(f'"{ref}"', board)

        bom = PROJECT_DIR / "docs" / "candidate_bom_sourcing.md"
        self.assertTrue(bom.exists())
        bom_text = bom.read_text(encoding="utf-8")
        self.assertIn("candidate engineering BOM only", bom_text)
        self.assertIn("G5Q-1A-DC5", bom_text)

    def test_draft_pcb_net_application_is_documented(self):
        script = REPO_ROOT / "scripts" / "apply-draft-pcb-nets.py"
        doc = PROJECT_DIR / "docs" / "draft_pcb_circuit_design.md"
        self.assertTrue(script.exists())
        self.assertTrue(doc.exists())

        doc_text = doc.read_text(encoding="utf-8")
        for net in ["ICM_24VAC_SOURCE", "HEAT_CHAIN_K1_K2", "TH_HEAT_REQUEST_OUT"]:
            self.assertIn(net, doc_text)


@unittest.skipUnless(shutil.which("kicad-cli"), "kicad-cli is not installed")
class KiCadCliTests(unittest.TestCase):
    def test_kicad_cli_checks_pass(self):
        result = subprocess.run(
            ["bash", "./scripts/kicad-check.sh"],
            cwd=REPO_ROOT,
            text=True,
            stdout=subprocess.PIPE,
            stderr=subprocess.STDOUT,
            check=False,
            timeout=120,
        )

        self.assertEqual(result.returncode, 0, result.stdout)

        drc = json.loads((REPO_ROOT / "reports" / "drc.json").read_text(encoding="utf-8"))
        self.assertEqual(drc["violations"], [], "Draft PCB should have no regular PCB DRC items")
        self.assertEqual(drc["unconnected_items"], [], "Draft PCB should have no unrouted PCB items")

        parity = json.loads((REPO_ROOT / "reports" / "drc-parity.json").read_text(encoding="utf-8"))
        self.assertEqual(parity["schematic_parity"], [], "Draft PCB should have no schematic parity items")

    def test_critical_heat_request_nets_are_applied_to_pcb(self):
        try:
            import pcbnew
        except ImportError as exc:
            self.skipTest(f"pcbnew Python module is not available: {exc}")

        board = pcbnew.LoadBoard(str(BOARD))
        refs = {fp.GetReference(): fp for fp in board.GetFootprints()}

        expected_pad_nets = {
            ("J2", "5"): "ICM_24VAC_SOURCE",
            ("K1", "2"): "ICM_24VAC_SOURCE",
            ("K1", "3"): "HEAT_CHAIN_K1_K2",
            ("K2", "2"): "HEAT_CHAIN_K1_K2",
            ("K2", "3"): "TH_HEAT_REQUEST_OUT",
            ("J2", "2"): "TH_HEAT_REQUEST_OUT",
        }

        for (ref, pad_no), net in expected_pad_nets.items():
            pads = {pad.GetNumber(): pad for pad in refs[ref].Pads()}
            self.assertEqual(pads[pad_no].GetNetname(), net)

        routed_nets = {track.GetNetname() for track in board.GetTracks()}
        for net in ["ICM_24VAC_SOURCE", "HEAT_CHAIN_K1_K2", "TH_HEAT_REQUEST_OUT"]:
            self.assertIn(net, routed_nets)

        route_layers = {
            (track.GetNetname(), board.GetLayerName(track.GetLayer()))
            for track in board.GetTracks()
        }
        self.assertIn(("ICM_24VAC_SOURCE", "F.Cu"), route_layers)
        self.assertIn(("HEAT_CHAIN_K1_K2", "B.Cu"), route_layers)
        self.assertIn(("TH_HEAT_REQUEST_OUT", "B.Cu"), route_layers)

    def test_power_tree_nets_are_applied_to_pcb(self):
        try:
            import pcbnew
        except ImportError as exc:
            self.skipTest(f"pcbnew Python module is not available: {exc}")

        board = pcbnew.LoadBoard(str(BOARD))
        refs = {fp.GetReference(): fp for fp in board.GetFootprints()}

        expected_pad_nets = {
            ("J1", "1"): "VAC24_A",
            ("J1", "2"): "VAC24_B",
            ("J1", "3"): "CHASSIS_SHIELD",
            ("F1", "1"): "VAC24_A_FUSED",
            ("F1", "2"): "VAC24_A",
            ("MOV1", "1"): "VAC24_A_FUSED",
            ("MOV1", "2"): "VAC24_B",
            ("TVS1", "1"): "VAC24_A_FUSED",
            ("TVS1", "2"): "VAC24_B",
            ("D1", "1"): "VAC24_A_FUSED",
            ("D1", "2"): "VAC24_B",
            ("D1", "3"): "VRAW",
            ("D1", "4"): "PGND_RAW",
            ("C1", "1"): "VRAW",
            ("C1", "2"): "PGND_RAW",
            ("U1", "1"): "PGND_RAW",
            ("U1", "2"): "VRAW",
            ("U1", "3"): "VRAW",
            ("U1", "4"): "RON_5V_TBD",
            ("U1", "5"): "FB_5V_TBD",
            ("U1", "6"): "+5V_PGOOD",
            ("U1", "7"): "BST_5V",
            ("U1", "8"): "SW_5V",
            ("U1", "9"): "PGND_RAW",
            ("L1", "1"): "SW_5V",
            ("L1", "2"): "+5V",
            ("C4", "1"): "VRAW",
            ("C4", "2"): "PGND_RAW",
            ("C5", "1"): "BST_5V",
            ("C5", "2"): "SW_5V",
            ("R5", "1"): "+5V",
            ("R5", "2"): "FB_5V_TBD",
            ("R6", "1"): "FB_5V_TBD",
            ("R6", "2"): "PGND_RAW",
            ("R7", "1"): "RON_5V_TBD",
            ("R7", "2"): "PGND_RAW",
            ("D2", "1"): "+5V_RELAY",
            ("D2", "2"): "K1_COIL_LOW",
            ("D3", "1"): "+5V_RELAY",
            ("D3", "2"): "K2_COIL_LOW",
            ("U2", "1"): "+3V3",
            ("U2", "2"): "+5V",
            ("U2", "3"): "+5V",
            ("U2", "4"): "SW_3V3",
            ("U2", "5"): "GND",
            ("U2", "6"): "BST_3V3",
            ("L2", "1"): "SW_3V3",
            ("L2", "2"): "+3V3",
            ("C6", "1"): "BST_3V3",
            ("C6", "2"): "SW_3V3",
            ("C7", "1"): "+5V",
            ("C7", "2"): "GND",
            ("C8", "1"): "+3V3",
            ("C8", "2"): "GND",
            ("U3", "1"): "BROWNOUT_OK",
            ("U3", "2"): "GND",
            ("U3", "3"): "+3V3",
            ("U5", "1"): "GND",
            ("U5", "2"): "+3V3",
            ("U6", "21"): "VAL_OPTO_GPIO",
            ("U6", "22"): "TH_OPTO_GPIO",
            ("U6", "23"): "IND_OPTO_GPIO",
            ("U6", "24"): "VAC24_OPTO_GPIO",
            ("R8", "1"): "VAL_SENSE_AC",
            ("R8", "2"): "VAL_OPTO_LIMIT_A",
            ("R9", "1"): "VAL_OPTO_LIMIT_A",
            ("R9", "2"): "VAL_OPTO_INPUT",
            ("R13", "1"): "TH_HEAT_REQUEST_OUT",
            ("R13", "2"): "TH_OPTO_LIMIT_A",
            ("R14", "1"): "TH_OPTO_LIMIT_A",
            ("R14", "2"): "TH_OPTO_INPUT",
            ("R15", "1"): "TH_OPTO_GPIO",
            ("R15", "2"): "+3V3",
            ("U9", "1"): "TH_OPTO_INPUT",
            ("U9", "2"): "ICM_GND_REF",
            ("U9", "4"): "GND",
            ("U9", "5"): "TH_OPTO_GPIO",
            ("R16", "1"): "IND_SENSE_AC",
            ("R16", "2"): "IND_OPTO_LIMIT_A",
            ("R17", "1"): "IND_OPTO_LIMIT_A",
            ("R17", "2"): "IND_OPTO_INPUT",
            ("R18", "1"): "IND_OPTO_GPIO",
            ("R18", "2"): "+3V3",
            ("U10", "1"): "IND_OPTO_INPUT",
            ("U10", "2"): "ICM_GND_REF",
            ("U10", "4"): "GND",
            ("U10", "5"): "IND_OPTO_GPIO",
            ("R19", "1"): "ICM_24VAC_SOURCE",
            ("R19", "2"): "VAC24_OPTO_LIMIT_A",
            ("R20", "1"): "VAC24_OPTO_LIMIT_A",
            ("R20", "2"): "VAC24_OPTO_INPUT",
            ("R21", "1"): "VAC24_OPTO_GPIO",
            ("R21", "2"): "+3V3",
            ("U12", "1"): "VAC24_OPTO_INPUT",
            ("U12", "2"): "ICM_GND_REF",
            ("U12", "4"): "GND",
            ("U12", "5"): "VAC24_OPTO_GPIO",
            ("U11", "1"): "VAL_OPTO_INPUT",
            ("U11", "2"): "ICM_GND_REF",
            ("U11", "4"): "GND",
            ("U11", "5"): "VAL_OPTO_GPIO",
            ("R10", "1"): "RELAY_K1_GATE",
            ("R10", "2"): "GND",
            ("R11", "1"): "RELAY_K2_GATE",
            ("R11", "2"): "GND",
            ("R22", "1"): "RELAY_K1_GATE_DRIVE",
            ("R22", "2"): "RELAY_K1_GATE",
            ("R23", "1"): "RELAY_K2_GATE_DRIVE",
            ("R23", "2"): "RELAY_K2_GATE",
            ("R24", "1"): "+3V3_ADC",
            ("R24", "2"): "THERMISTOR_ADC",
            ("R25", "1"): "+3V3",
            ("R25", "2"): "I2C_SDA",
            ("R26", "1"): "+3V3",
            ("R26", "2"): "I2C_SCL",
            ("R27", "1"): "SFS_INPUT",
            ("R27", "2"): "SFS_FIELD_INPUT",
            ("R28", "1"): "VRAW",
            ("R28", "2"): "VRAW_MONITOR_ADC",
            ("R29", "1"): "VRAW_MONITOR_ADC",
            ("R29", "2"): "AGND",
            ("R30", "1"): "+3V3",
            ("R30", "2"): "THERMISTOR_RANGE_OK",
            ("R31", "1"): "+3V3",
            ("R31", "2"): "SFS_RANGE_OK",
            ("R32", "1"): "+3V3_ADC",
            ("R32", "2"): "THERM_LOW_REF_TBD",
            ("R33", "1"): "THERM_LOW_REF_TBD",
            ("R33", "2"): "AGND",
            ("R34", "1"): "+3V3_ADC",
            ("R34", "2"): "THERM_HIGH_REF_TBD",
            ("R35", "1"): "THERM_HIGH_REF_TBD",
            ("R35", "2"): "AGND",
            ("R36", "1"): "+3V3_ADC",
            ("R36", "2"): "SFS_LOW_REF_TBD",
            ("R37", "1"): "SFS_LOW_REF_TBD",
            ("R37", "2"): "AGND",
            ("R38", "1"): "+3V3_ADC",
            ("R38", "2"): "SFS_HIGH_REF_TBD",
            ("R39", "1"): "SFS_HIGH_REF_TBD",
            ("R39", "2"): "AGND",
            ("C9", "1"): "THERMISTOR_ADC",
            ("C9", "2"): "AGND",
            ("C10", "1"): "SFS_ADC",
            ("C10", "2"): "AGND",
            ("C11", "1"): "VRAW_MONITOR_ADC",
            ("C11", "2"): "AGND",
            ("U7", "8"): "VRAW_MONITOR_ADC",
            ("R12", "1"): "VAL_OPTO_GPIO",
            ("R12", "2"): "+3V3",
            ("Q1", "2"): "GND",
            ("Q2", "2"): "GND",
            ("TP1", "1"): "VRAW",
            ("TP2", "1"): "+5V",
            ("TP3", "1"): "+3V3",
            ("TP4", "1"): "WATCHDOG_OK",
            ("TP5", "1"): "SAFETY_STATIC_OK",
            ("TP6", "1"): "K1_COIL_LOW",
            ("TP7", "1"): "K2_COIL_LOW",
            ("TP8", "1"): "TH_FEEDBACK",
            ("TP9", "1"): "VAL_SENSE_AC",
        }

        for (ref, pad_no), net in expected_pad_nets.items():
            pads = [pad for pad in refs[ref].Pads() if pad.GetNumber() == pad_no]
            self.assertTrue(pads, f"{ref} pad {pad_no} should exist")
            for pad in pads:
                self.assertEqual(pad.GetNetname(), net)

        self.assertEqual(refs["D1"].GetFPIDAsString(), "Diode_SMD:Diode_Bridge_Vishay_MBLS")
        self.assertEqual(refs["U1"].GetFPIDAsString(), "Package_SO:TI_SO-PowerPAD-8")

        routed_nets = {track.GetNetname() for track in board.GetTracks()}
        for net in [
            "VAC24_A_FUSED", "VAC24_B", "VRAW", "PGND_RAW", "SW_5V", "BST_5V", "+5V", "+3V3", "+5V_RELAY",
            "K1_COIL_LOW", "K2_COIL_LOW", "REMOTE_SPA_SENSE", "REMOTE_POOL_SENSE",
            "SPA_LINE", "POOL_LINE", "ISO_REMOTE_5V",
            "SPA_LED_A", "POOL_LED_A", "WATCHDOG_OK", "VAL_SENSE_AC",
            "VAL_OPTO_LIMIT_A", "VAL_OPTO_INPUT", "ICM_GND_REF", "VAL_OPTO_GPIO",
            "TH_OPTO_LIMIT_A", "TH_OPTO_INPUT", "TH_OPTO_GPIO",
            "IND_SENSE_AC", "IND_OPTO_LIMIT_A", "IND_OPTO_INPUT", "IND_OPTO_GPIO",
            "VAC24_OPTO_LIMIT_A", "VAC24_OPTO_INPUT", "VAC24_OPTO_GPIO",
            "RELAY_K1_GATE", "RELAY_K2_GATE",
            "+3V3_ADC", "AGND", "THERMISTOR_ADC",
            "I2C_SDA", "I2C_SCL",
            "SFS_INPUT", "SFS_FIELD_INPUT", "SFS_ADC", "VRAW_MONITOR_ADC",
            "THERMISTOR_RANGE_OK", "SFS_RANGE_OK",
            "THERM_LOW_REF_TBD", "THERM_HIGH_REF_TBD", "SFS_LOW_REF_TBD", "SFS_HIGH_REF_TBD",
        ]:
            self.assertIn(net, routed_nets)

        via_nets = {
            track.GetNetname()
            for track in board.GetTracks()
            if isinstance(track, pcbnew.PCB_VIA)
        }
        for net in ["GND", "+5V", "PGND_RAW", "WATCHDOG_OK", "VAC24_A_FUSED", "BST_5V", "VAL_SENSE_AC", "TH_OPTO_GPIO", "IND_OPTO_GPIO", "IND_SENSE_AC", "VAC24_OPTO_GPIO", "ICM_24VAC_SOURCE", "THERMISTOR_ADC", "I2C_SDA", "I2C_SCL", "SFS_INPUT", "SFS_ADC", "VRAW_MONITOR_ADC", "THERM_LOW_REF_TBD", "THERM_HIGH_REF_TBD", "SFS_LOW_REF_TBD", "SFS_HIGH_REF_TBD"]:
            self.assertIn(net, via_nets)

    def test_manufacturing_silkscreen_warnings_are_readable(self):
        try:
            import pcbnew
        except ImportError as exc:
            self.skipTest(f"pcbnew Python module is not available: {exc}")

        board = pcbnew.LoadBoard(str(BOARD))
        silk_texts = {}
        for drawing in board.GetDrawings():
            if not isinstance(drawing, pcbnew.PCB_TEXT):
                continue
            if board.GetLayerName(drawing.GetLayer()) != "F.Silkscreen":
                continue
            silk_texts[drawing.GetText()] = drawing

        expected_warnings = {
            "NO LINE VOLTAGE": (1.20, 0.18),
            "VAL / GAS MONITOR ONLY - NO DRIVE": (0.90, 0.14),
            "24 VAC FIELD / POWER ZONE": (1.50, 0.20),
            "ESP32 / LOGIC ZONE": (1.50, 0.20),
        }
        for text, (min_height, min_thickness) in expected_warnings.items():
            self.assertIn(text, silk_texts)
            self.assertGreaterEqual(pcbnew.ToMM(silk_texts[text].GetTextHeight()), min_height)
            self.assertGreaterEqual(pcbnew.ToMM(silk_texts[text].GetTextThickness()), min_thickness)


if __name__ == "__main__":
    unittest.main()

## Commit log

2026-05-31 AI gen
    [esp32_supervisor.kicad_sch, icm_interface.kicad_sch, mastertemp_esp32.kicad_pcb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]
2026-05-31 Starting design
    [mastertemp_esp32.kicad_pcb]
2026-06-01 Make open source.
    [esp32_supervisor.kicad_sch, icm_interface.kicad_sch, power_24vac.kicad_sch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]
